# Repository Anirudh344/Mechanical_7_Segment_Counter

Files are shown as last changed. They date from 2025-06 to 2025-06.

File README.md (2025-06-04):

Mechanical 7-Segment Counter
Course: ME-395 Engineering Practicum-2
Professor-in-Charge: Dr. Murshid Imam

🧑‍🤝‍🧑 Group Members
Anirudh Singh (2201ME11)

Aryan Kaushal (2201ME16)

Ashutosh Tiwari (2201ME18)

Asmit Singh (2201ME20)

Harsh Kumar (2201ME30)

📌 Objective
Design and implementation of a mechanical 7-segment counter driven by cams and gears. The counter displays digits from 0 to 9 through a push-button mechanism and automatically resets after reaching 9. All components are designed for 3D printing using PLA (Polylactic Acid).
| Part | Quantity |
| --- | --- |
| Cams | 8 |
| Followers | 7 |
| Segments | 7 |
| Screws | 4 |
| Springs | 2 |
| Gears | 4 |
| Plates | 3 |
| Shaft | 1 |
| Pushbutton | 1 |
| Rubber Bands | 2 |
📖 Theory
The mechanism uses a ratchet and pawl system to enforce unidirectional motion. It:

Converts continuous button presses into intermittent camshaft rotation.

Ensures one-way counting (0 to 9), and automatic reset to 0 after 9.

Minimizes component wear and stress for improved longevity.

⚙️ Working Principle
1. Seven-Segment Mechanism
Each segment has two states: ON or OFF.

A camshaft with 8 cams controls the states.

Springs retract segments to OFF; cams push them ON.

2. Camshaft Design
Camshaft rotates in 10 steps (36° per step).

Each cam profile corresponds to one digit (0–9).

Varying lift and dwell angles ensure correct segment combinations.

3. Gear and Key Mechanism
A gear train rotates the camshaft.

A ratchet and pawl mechanism ensures precise 36° step increments per push.

4. Reset Mechanism
After the 9th position, camshaft automatically resets to 0.

Achieved by full 360° rotation across 10 button presses.

5. Segment Control
Each segment is a lever actuated by cams.

Springs/rubber bands bring segments back to OFF state.

📐 Calculations
Rotation per digit = 360° / 10 = 36°

Cam positions determined based on required ON/OFF segments per digit.

3D CAD Models designed in SolidWorks.

🧪 Innovation and Applications
Sensor Integration:

Replace push button with electric, thermal, or proximity sensors.

Allows use in automated or hostile environments.

Application Scenarios:

Industrial impact monitoring (hammering, punching, etc.)

Deep-sea equipment counters.

Radiation monitoring in nuclear or fusion reactors.

📏 Optimization
Compact design for space efficiency.

Fewer moving parts to simplify mechanics.

Use of rubber bands instead of multiple springs for easier assembly.

🎯 Future Goals
Integrate sensors for hands-free operation.

Enable multi-digit display counters.

Explore commercialization of the product.

🖼️ CAD Designs and Prints
✅ Cam profiles and followers modeled in SolidWorks.

✅ 2D and 3D assemblies prepared for 3D printing.

✅ Fully functional prototype tested and validated.

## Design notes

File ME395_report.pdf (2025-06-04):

ME-395

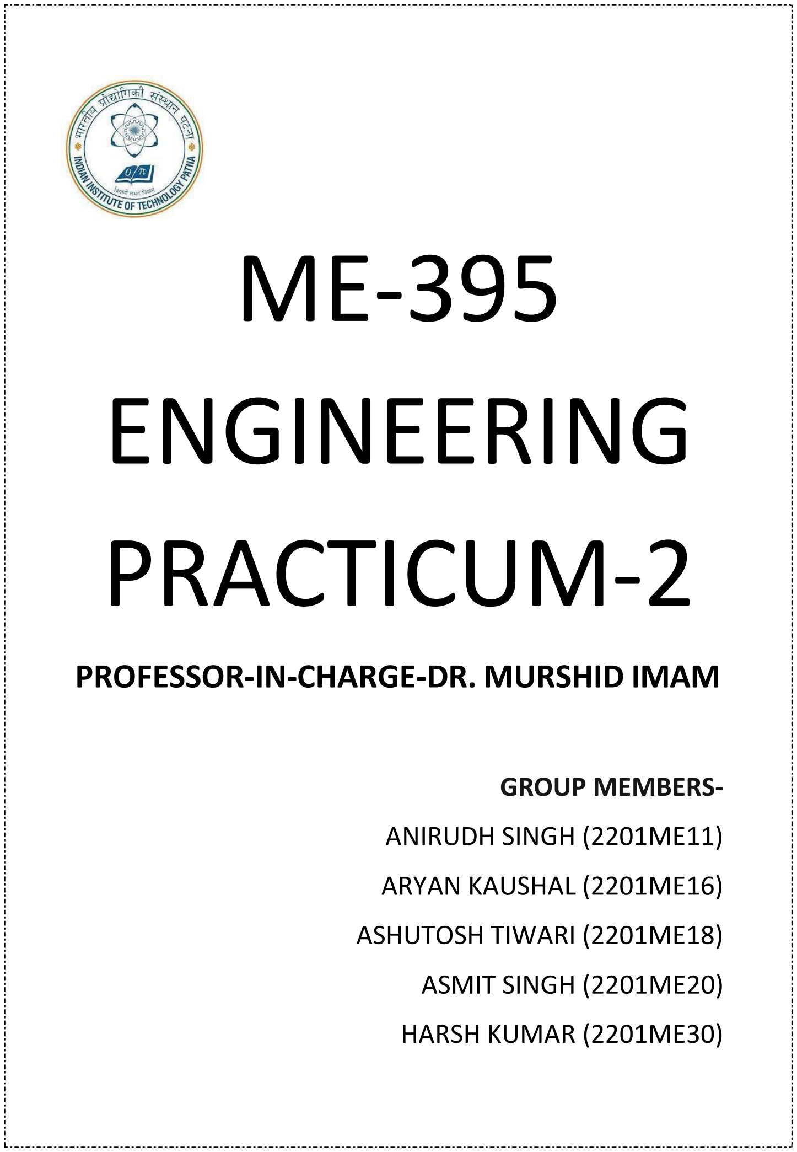
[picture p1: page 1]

# ENGINEERING PRACTICUM-2

# PROFESSOR-IN-CHARGE-DR. MURSHID IMAM

## GROUP MEMBERS-

## ANIRUDH SINGH (2201ME11)

## ARYAN KAUSHAL (2201ME16)

## ASHUTOSH TIWARI (2201ME18)

## ASMIT SINGH (2201ME20)

## HARSH KUMAR (2201ME30)

OBJECTIVE- Design and implementation of a mechanical seven-Segment Counter Driven by Cams and Gears.

PARTS REQUIRED- Cams (8), Followers (7), Segments (7), Screw (4), Springs (2), Gears (4), Plates (3), Shaft (1), Pushbutton (1), Rubber bands (2).

All parts are to be 3D-printed and made from Polylactic Acid (PLA) material.

## THEORY-

Ratchet and Pawl Mechanism is used in various engineering instruments that support one way motion and used to prevent motion in opposite direction. Ratchet mechanism also converts continuous motion into intermittent motion. In seven segment counters if we press the push button in a continuous manner, it will show the numbers one at a time.

We have designed the push button and spring in a way that it can only goes from 0 to 9 and then reset to 0 without requiring any manual intervention, it can’t go in reverse manner.

This mechanism also help us to minimize the wear in the components as counter counts in only one direction, reduces the stress in the components that results in longer working life.

## WORKING PRINCIPLE-

### 1. Seven-Segment Mechanism:

- Each of the seven segments have two states: ON or OFF.
- WE ARE Using a camshaft to control the segments.
- Either pushing a segment into the OFF position or let it stay ON.
- WE are using 8 CAMs.

### 2. Camshaft Design:

- The camshaft will rotate in 10 steps, with each step corresponding to a new number.
- For each step (0–9), the cam profiles will determine which segments are engaged

- We have designed the cam profiles such that each number gets its unique combination of segments by varying the lift and dwell angles.

### 3. Gears and Key Mechanism-

- We are using gear train to control the rotation of the camshaft.
- The key mechanism is connected to a ratchet and pawl system that advances the camshaft by a fixed increment with each rotation (e.g., 36° for each of the 10 positions).

### 4. Reset Mechanism:

- After the ninth position (number 9), the camshaft should reset to the first position (number 0).
- We are achieving this by ensuring that making sure that after 10 rotation each cam is its initial state because it had already rotated by 360 degrees.

### 5. Segment Control Layout:

- Each segment of the display is a lever that is pushed by the cam into the ON position and retracted into the OFF position by a spring.

## Calculations:

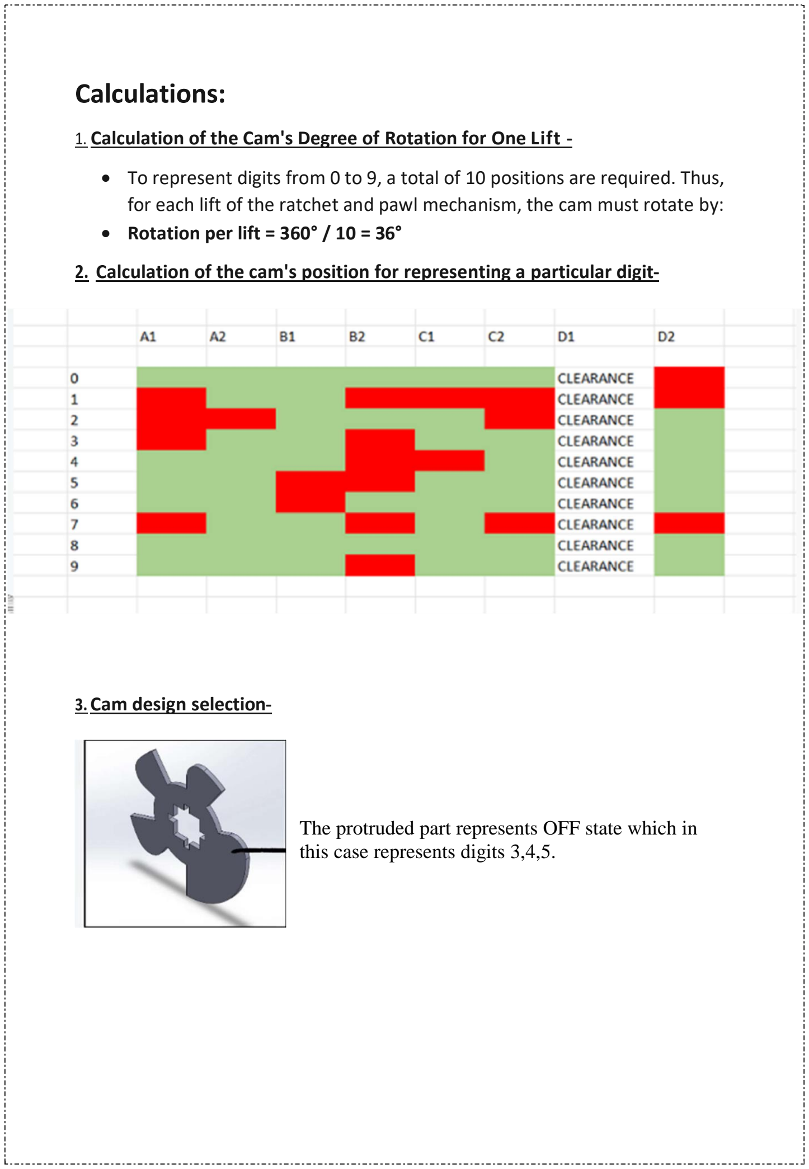
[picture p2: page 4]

1. Calculation of the Cam's Degree of Rotation for One Lift -
- To represent digits from 0 to 9, a total of 10 positions are required. Thus, for each lift of the ratchet and pawl mechanism, the cam must rotate by:
- Rotation per lift = 360° / 10 = 36°

### 2. Calculation of the cam's position for representing a particular digit-

### 3. Cam design selection-

The protruded part represents OFF state which in this case represents digits 3,4,5.

## Parts (cams) Created in Solidworks:

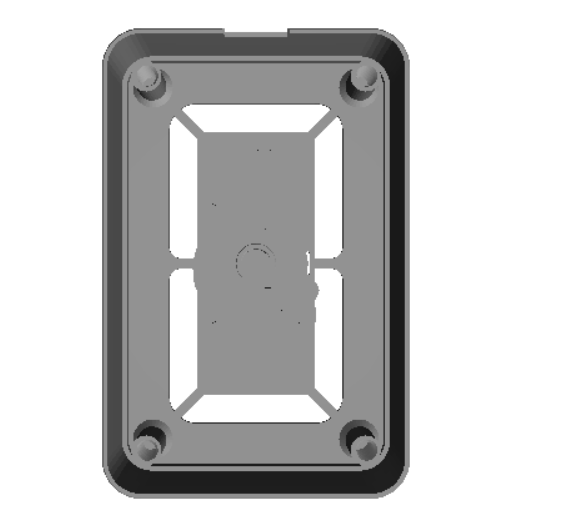
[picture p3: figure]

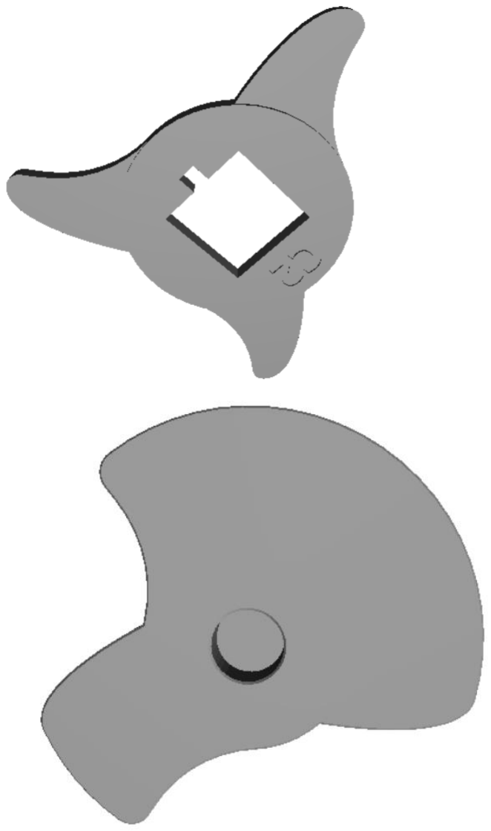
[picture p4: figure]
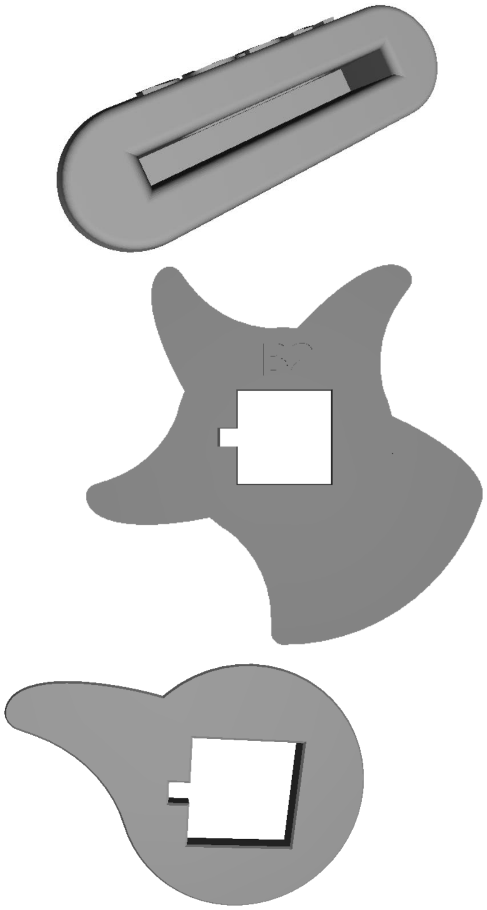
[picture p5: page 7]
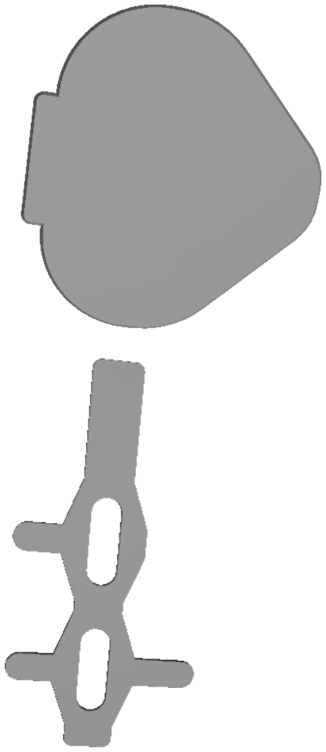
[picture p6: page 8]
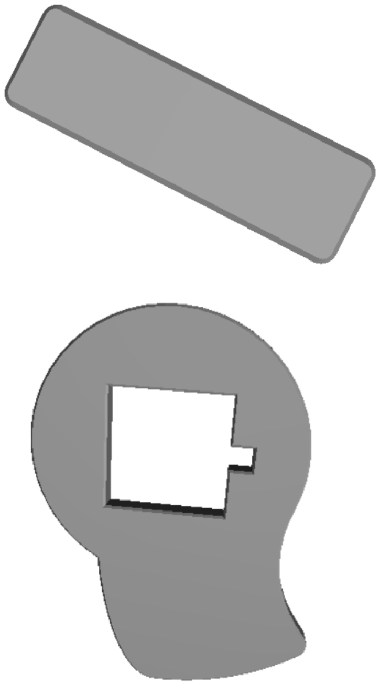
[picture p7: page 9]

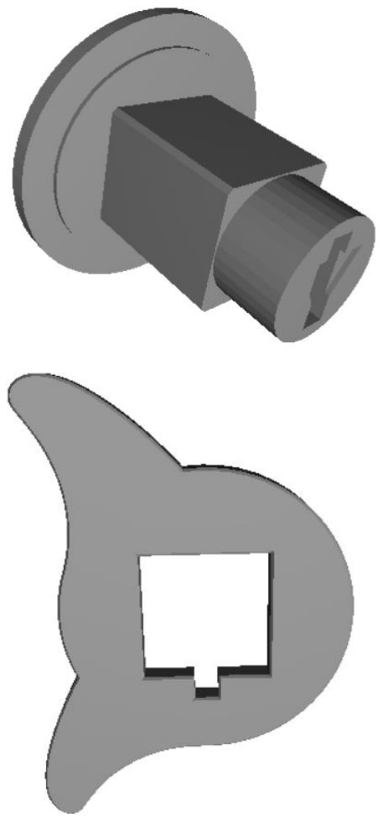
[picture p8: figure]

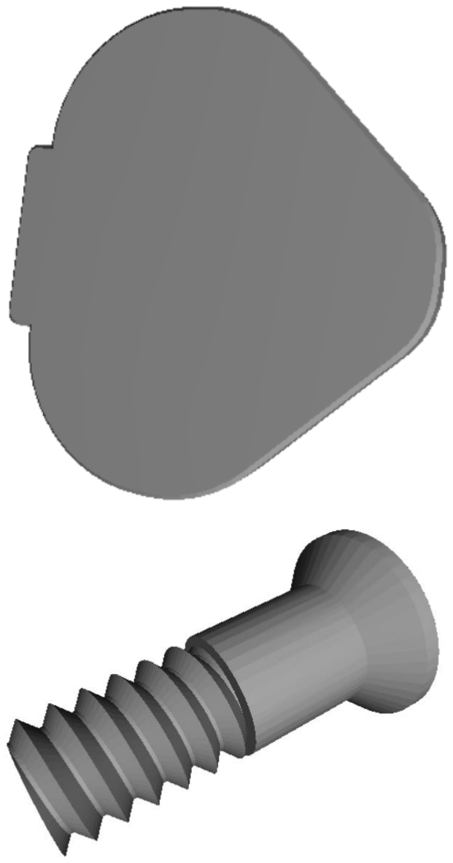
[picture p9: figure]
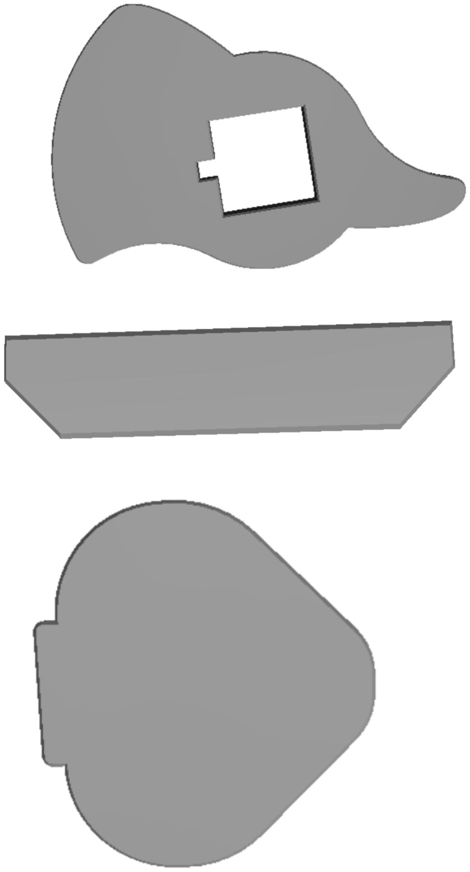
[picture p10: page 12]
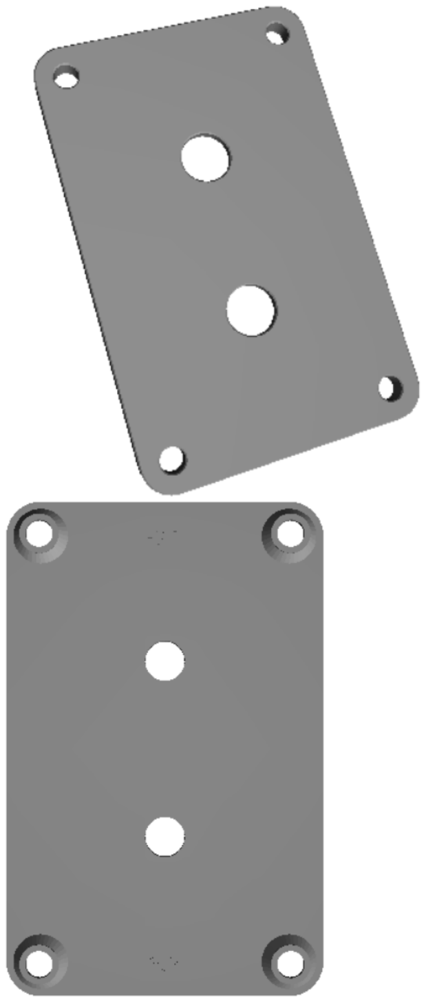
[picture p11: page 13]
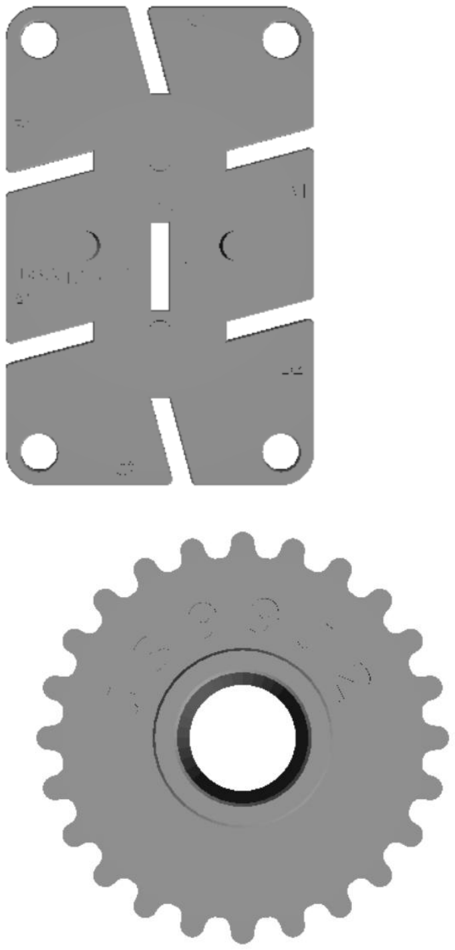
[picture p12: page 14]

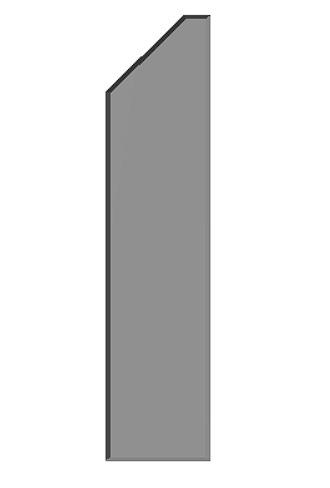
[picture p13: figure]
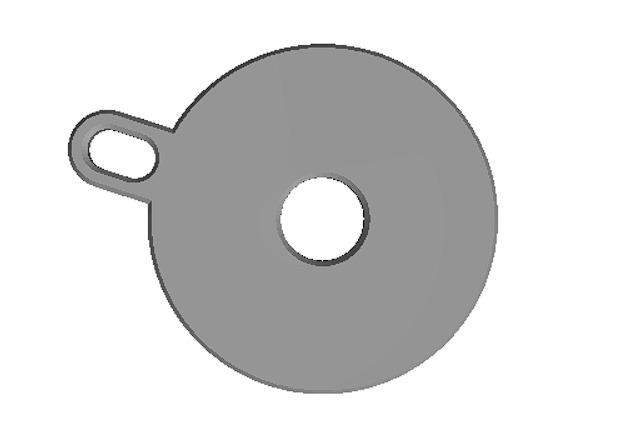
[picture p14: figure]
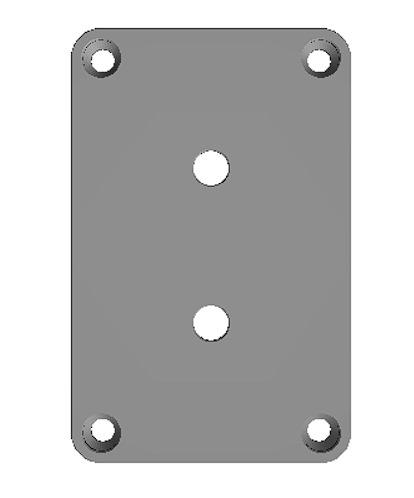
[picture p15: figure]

## 3-D PRINTED MODELS:

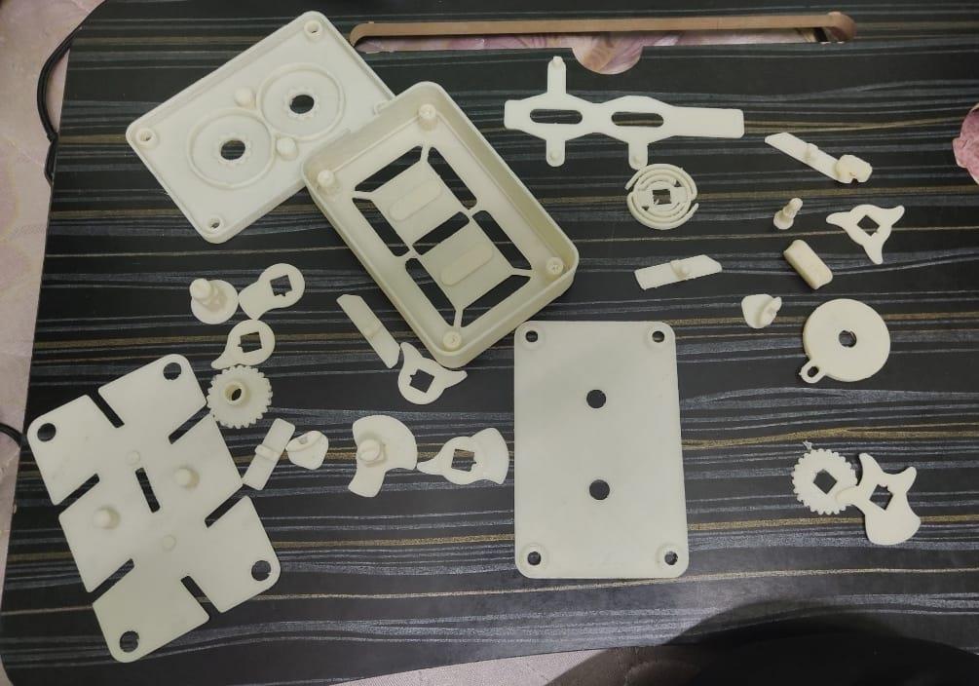
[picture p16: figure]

## 2-D Design of Model-

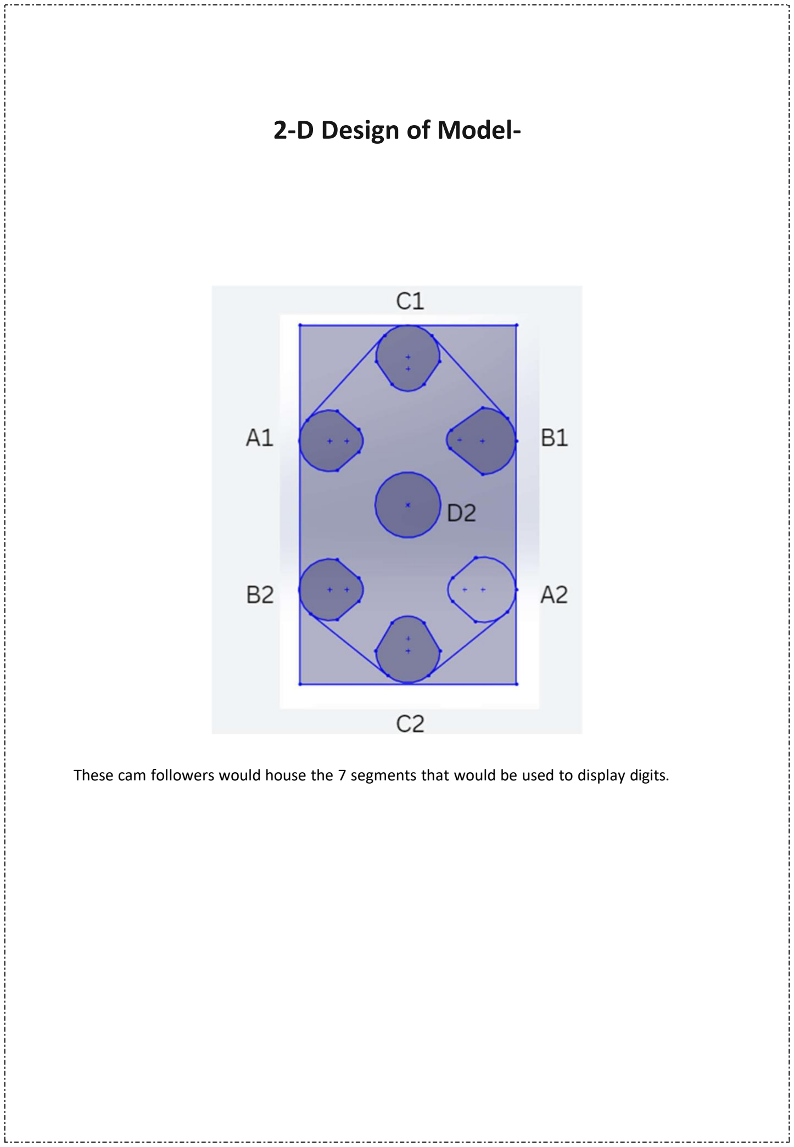
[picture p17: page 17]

These cam followers would house the 7 segments that would be used to display digits.

## 3-D Design of Model-

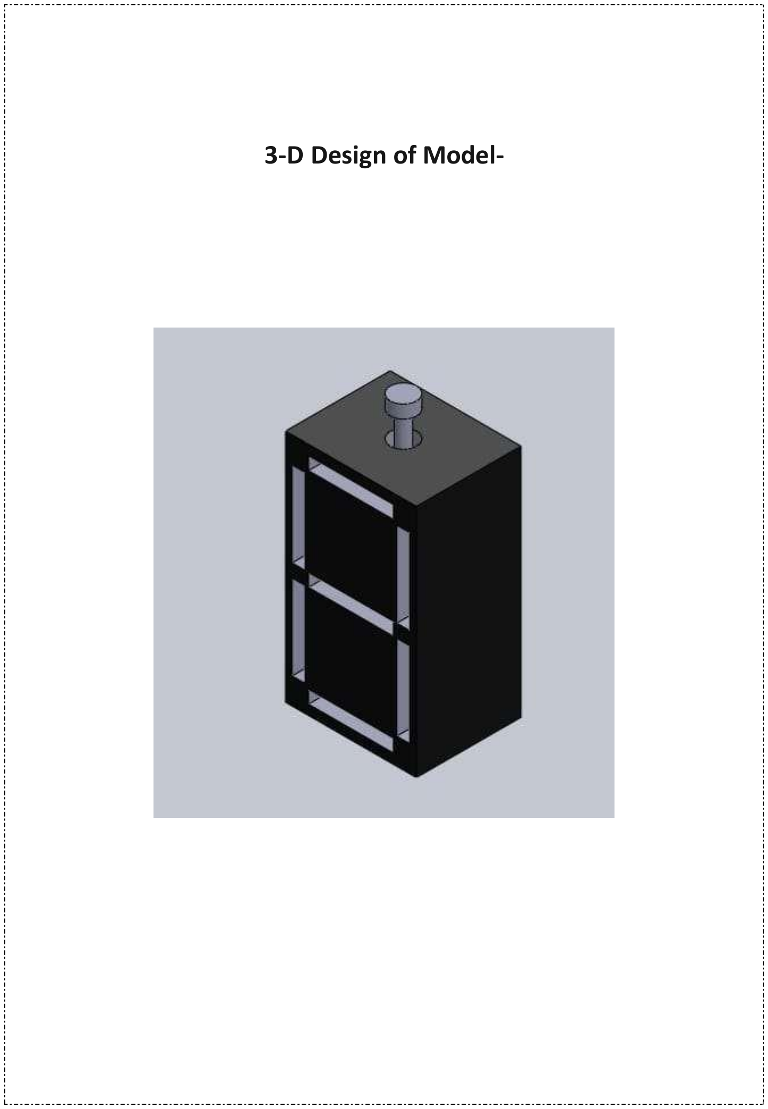
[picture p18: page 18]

## Innovation and Application:

- Since the push button is the trigger involved here, we can use different types of sensors corresponding to varying physical conditions which will activate it.
- Some of the sensors involved are electric, heat, and proximity sensors.
- This allows us to use the counter without manual labour or in extreme physical situations where human intervention is difficult.
- Mechanical processes such as hammering, pressing, and punching, which helps to monitor the number of impacts.
- High-pressure environments, such as the deep sea to keep track of equipment usage or structural monitoring.
- In nuclear reactors to detect and measure radiation or particle flux for monitoring, safety, and operational control.
- In high temperature and magnetic fields to measure radiation and particle flux in environments like fusion reactors and accelerators with designs to withstand extreme conditions.

## Optimization:

- Size optimization: A compact design reduces the size of parts while keeping the display clear, using smaller parts and segments to take up less space.
- Fewer moving parts: Reduce the number of mechanical components involved in segment movement, making the system simpler and easier to operate.
- Use of rubber bands instead of multiple springs for the cam return mechanism.

## Future goals:

- Enhancing practical usability by integrating sensors
- Drive product commercialization
- Convert to a multi-digit format

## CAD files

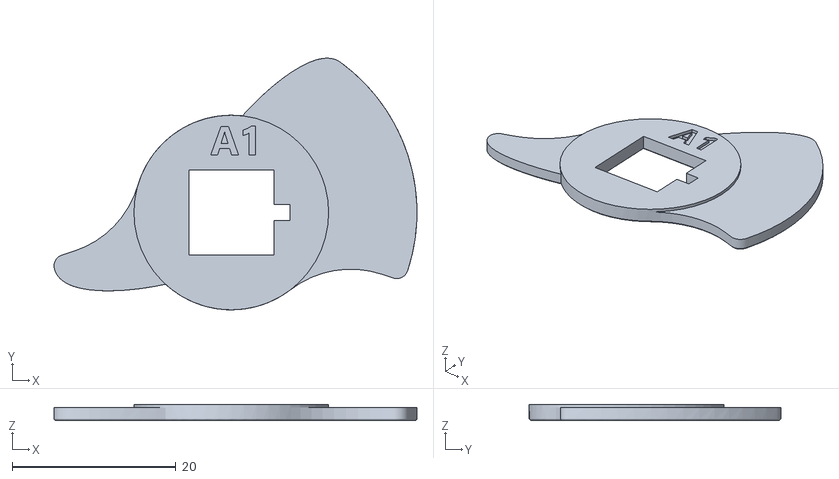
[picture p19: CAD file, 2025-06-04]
CAM_A1.STL
44.4 x 30.8 x 2.00

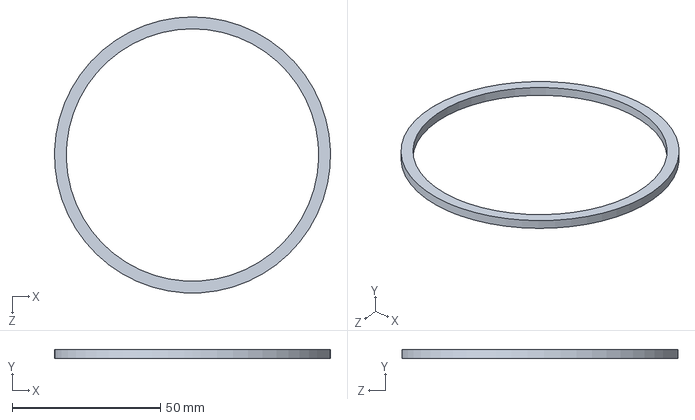
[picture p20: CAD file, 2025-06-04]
piston ring.SLDPRT
93.0 x 3.00 x 93.0 mm

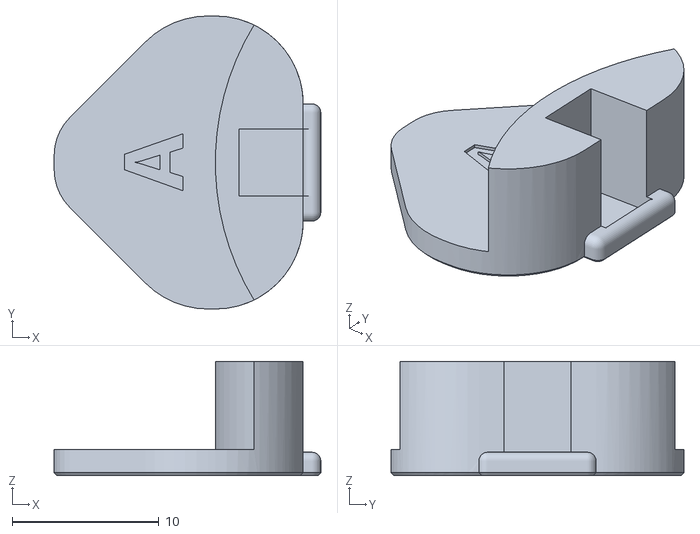
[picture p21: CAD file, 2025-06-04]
FOLLOWER_A.STL
18.2 x 20.0 x 7.80

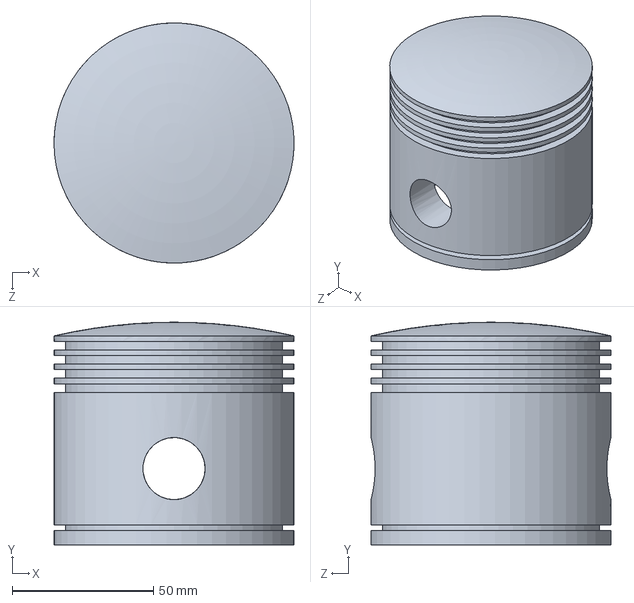
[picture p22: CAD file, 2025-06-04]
piston.SLDPRT
85.0 x 78.8 x 85.0 mm

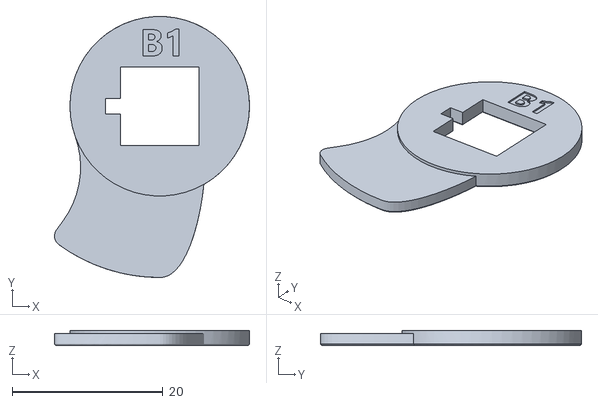
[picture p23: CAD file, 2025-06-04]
CAM_B1.STL
25.8 x 34.6 x 2.00

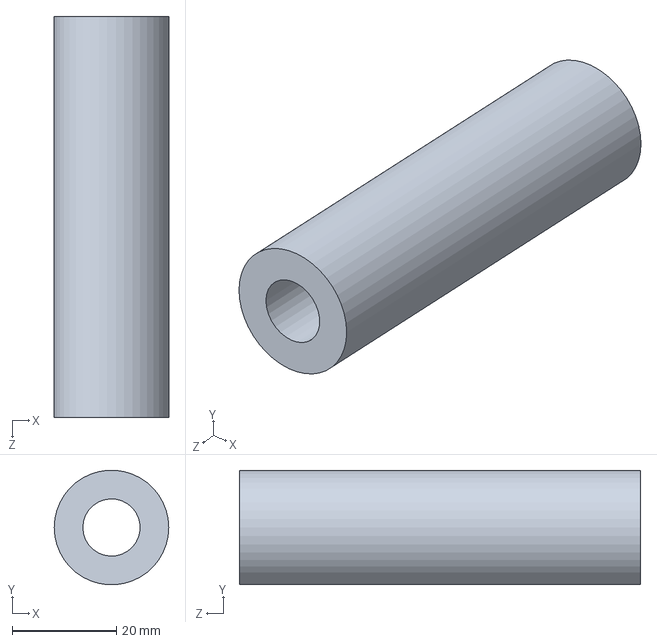
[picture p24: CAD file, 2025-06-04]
piston pin.SLDPRT
22.0 x 21.9 x 77.0 mm

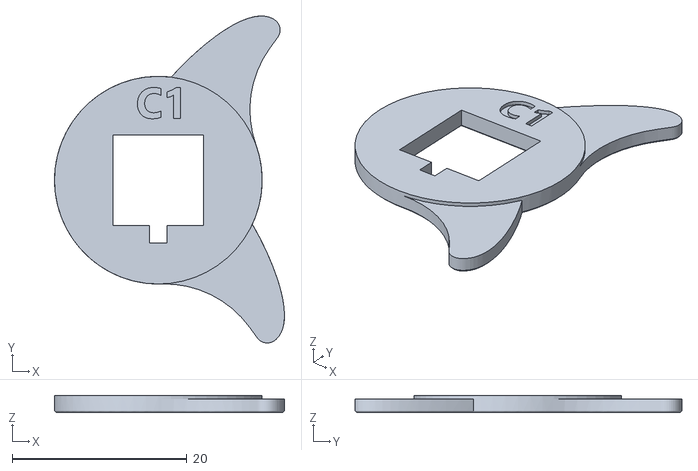
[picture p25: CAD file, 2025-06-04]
CAM_C1.STL
26.4 x 37.5 x 2.00

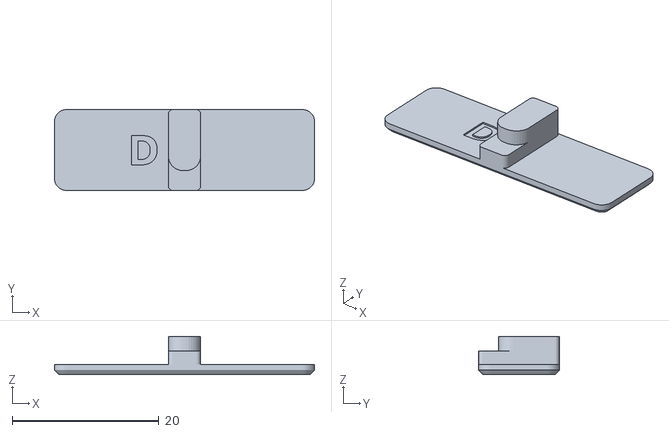
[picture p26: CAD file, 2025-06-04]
SEG_D.STL
35.4 x 11.0 x 5.20

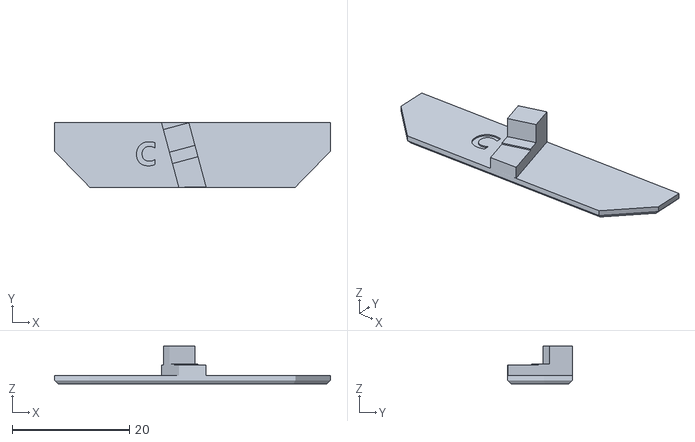
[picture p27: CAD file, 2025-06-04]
SEG_C.STL
47.0 x 11.0 x 6.40

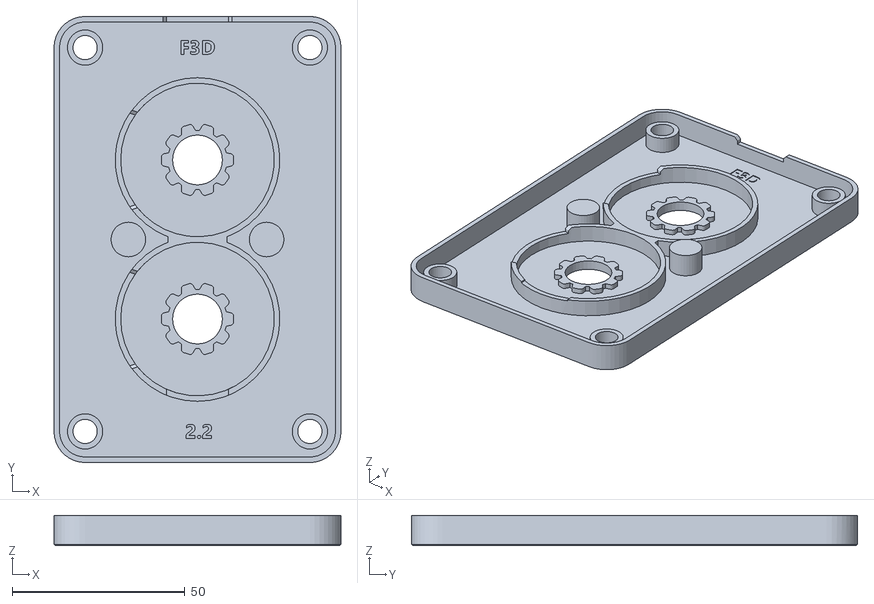
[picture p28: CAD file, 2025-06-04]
MID_PLATE_v2.2.STL
83.0 x 129.0 x 8.80

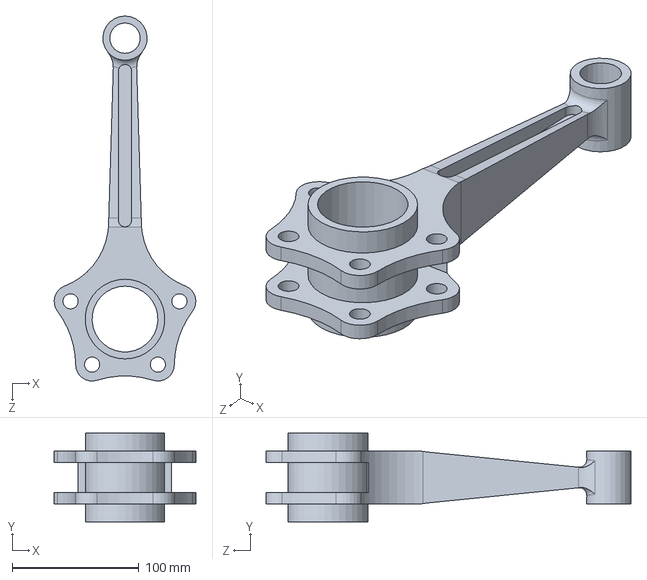
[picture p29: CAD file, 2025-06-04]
Master rof.SLDPRT
112.0 x 70.0 x 288.5 mm

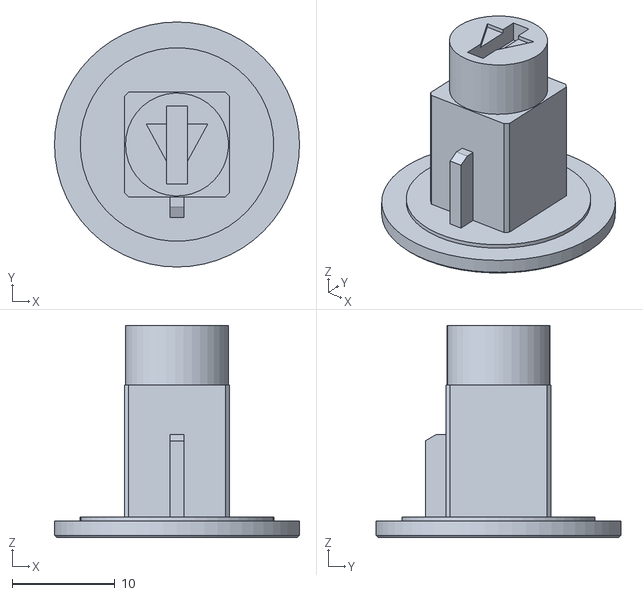
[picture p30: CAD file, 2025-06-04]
CAM_D1.STL
23.8 x 23.8 x 20.6

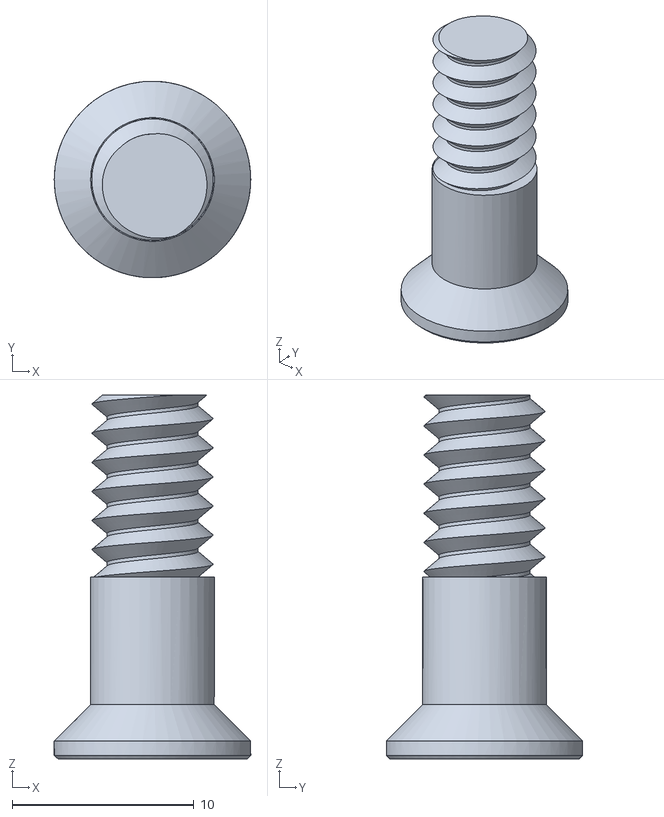
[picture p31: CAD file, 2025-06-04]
SCREW_v2.2.STL
10.8 x 10.8 x 20.0
